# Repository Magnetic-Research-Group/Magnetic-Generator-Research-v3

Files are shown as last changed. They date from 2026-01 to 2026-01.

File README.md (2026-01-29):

# Open Source Magnetic Generator Research Platform (v3.9.2)

Zenodo Archive https://doi.org/10.5281/zenodo.18370596

Project Status Update (v3.9.2 and Forward)

After running more rigorous simulations and completing a deeper engineering audit, we identified limitations in the v3.9.2 architecture that made it unsuitable for the level of validation and measurement rigor we are aiming for. Rather than continuing forward with known gaps, we made a deliberate decision to pivot the electronics and control architecture. The revised direction is inspired by Joule Thief–style regenerative behavior, but is implemented in a fundamentally different and more controlled way, suitable for scalable testing and proper energy accounting.

What remains valid in v3: The mechanical design and STL files remain valid and may be freely used to print and assemble the physical generator. The v3 repository is retained as a historical and mechanical reference.

What is changing: The electronics, control logic, and power architecture beyond v3.9.2 are under active redesign. The newer architecture is not represented in the v3 branch and should not be considered an incremental update to it. 

Current architecture (in development): Uses ferrite-core bifilar coils, replicated across the full matrix (55 coils total). Each physical coil contains two electrically independent windings. Regenerative behavior is actively coordinated by a microcontroller, rather than relying on purely passive oscillation. The goal is to study whether JT-like flyback recovery can be synchronized, gated, and measured safely at scale, with explicit current limiting, protection, and instrumentation.

Current focus: Empirical validation at low voltage (24 V) and modest power levels (tens of watts up to ~100 W). Verifying switching behavior, timing, thermal limits, and measurement methodology before any higher-voltage or higher-power work is considered. Future updates will be published as the redesigned electronics and control system mature. Please continue to check the repository for new releases and documentation.

## Project Overview
This repository contains the complete design files and engineering documentation for a 55-coil drum-style electromechanical test platform. The system is designed as an educational tool to rigorously investigate control strategies for pulsed magnetic interaction, specifically exploring the angle-timed impulse ("timed push") mechanical oscillator concept (evaluated experimentally).

## Purpose
The goal of this project is to provide a standardized, reproducible hardware platform for researchers to:
1. Study the effects of precise pulse timing on rotor momentum.
2. Evaluate the efficiency of series-aiding bifilar coil geometries.
3. Perform honest, measurement-based energy accounting (input versus harvest).

**Disclaimer:** This project is strictly educational. No claims are made regarding net-energy gain or sustained operation. Any conclusions drawn from this hardware must be based on verifiable metrology.

## Contents
* **Documentation:** Full Student Build Guide including wiring diagrams, theory of operation, and safety protocols.
* **CAD:** Complete FreeCAD source files and print-ready STL files for the 96 mm rotor / 160 mm stator architecture.
* **Code:** Reserved directory for future reference firmware related to timing control and experimental evaluation.

## License
* **Hardware:** CERN Open Hardware Licence v2 – Weakly Reciprocal (CERN-OHL-W)
* **Documentation:** Creative Commons Attribution-ShareAlike 4.0 (CC BY-SA 4.0)

## Dedication
Dedicated to the memory of Andrei Slobodian and the preservation of his electromechanical concepts for public study.

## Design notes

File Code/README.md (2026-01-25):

# Control Firmware (Placeholder)

This directory is intentionally reserved for future reference firmware related to:

- Timing control and pulse scheduling
- Hall sensor and encoder interfacing
- Data logging and measurement support
- Experimental control strategies for the magnetic generator test platform

## No Firmware in This Release

No control software is included in this release.

All timing strategies, pulse widths, sequencing logic, and optimization methods are deliberately **unspecified** to allow independent researchers to:

- Implement their own control approaches
- Avoid bias introduced by a single reference algorithm
- Perform independent verification and comparison

## Future Releases

Any firmware published here in the future will be:

- Clearly labeled as **experimental reference code**
- Accompanied by measurement context and limitations
- Explicitly non-optimized
- Released without performance, efficiency, or self-sustainment claims

This separation between hardware disclosure and control logic is intentional and aligns with best practices for open, reproducible experimental research.

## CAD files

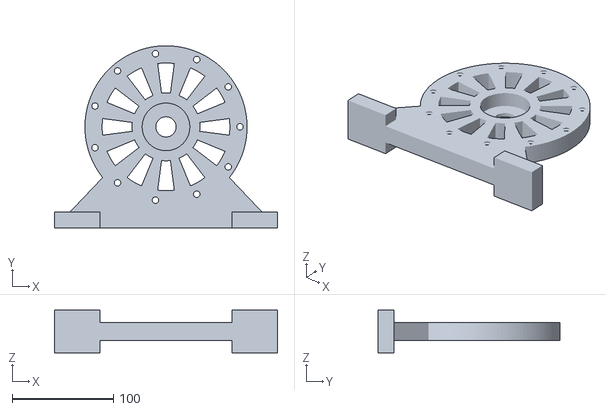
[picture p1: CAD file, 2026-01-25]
CAD/EndCapStand_V13_LeftRight_OnePiece_SideBySide-EndCap_Stand_V13_Right_OnePiece.stl
220.0 x 180.0 x 42.0

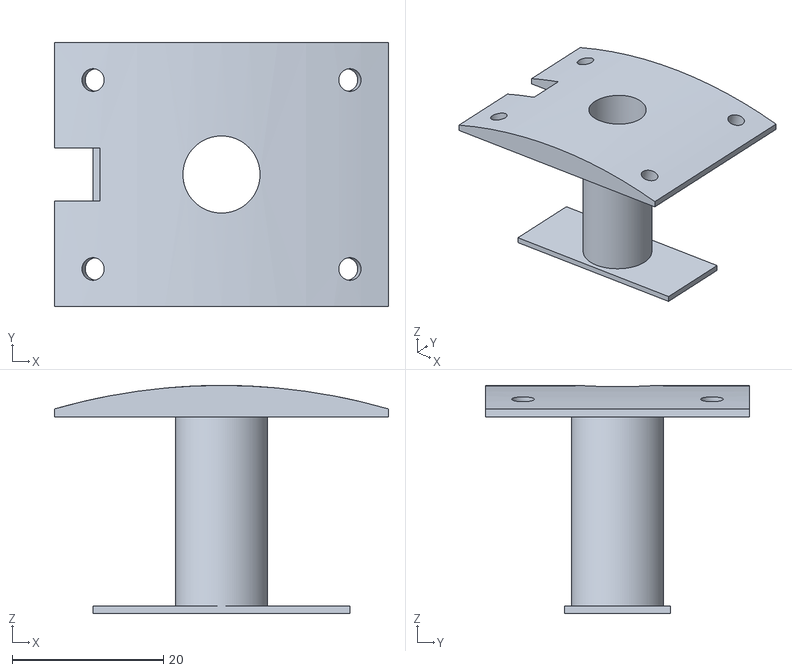
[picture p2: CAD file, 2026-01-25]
CAD/Coil_Module_V20_OD160_GAP10_LOCKED10_PASS1-Coil_Module_V20_OD160_GAP10_LOCKED10_PASS.stl
44.2 x 35.0 x 30.2

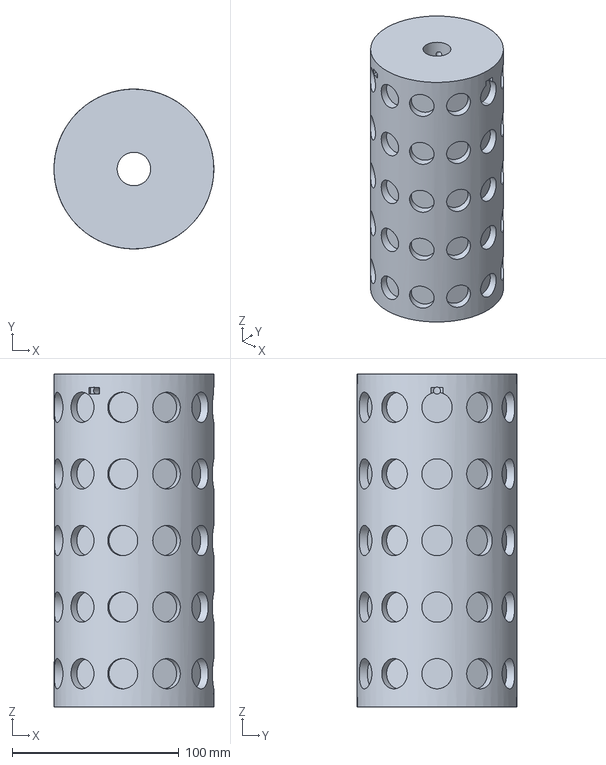
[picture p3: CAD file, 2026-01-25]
CAD/Rotor_V9_96mm_18x6_shaft20.FCStd
95.9 x 96.0 x 200.0 mm

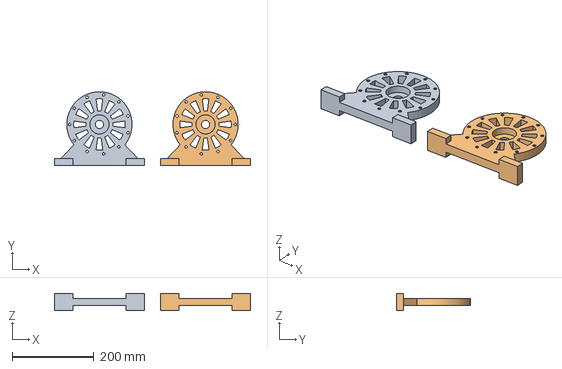
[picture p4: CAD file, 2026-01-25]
CAD/EndCapStand_V13_LeftRight_OnePiece_SideBySide.FCStd
480.0 x 180.0 x 42.0 mm
EndCap_Stand_V13_Left_OnePiece
EndCap_Stand_V13_Right_OnePiece

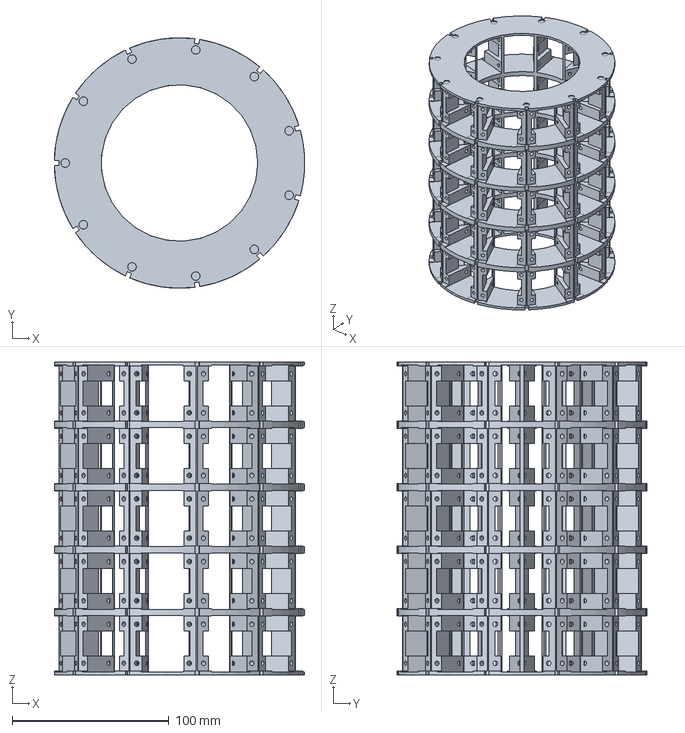
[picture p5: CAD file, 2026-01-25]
CAD/Stator_V11_OD160_ID100_CoilV19_LOCKED23G_LIP05_M3VISIBLE.FCStd
160.0 x 160.0 x 200.0 mm

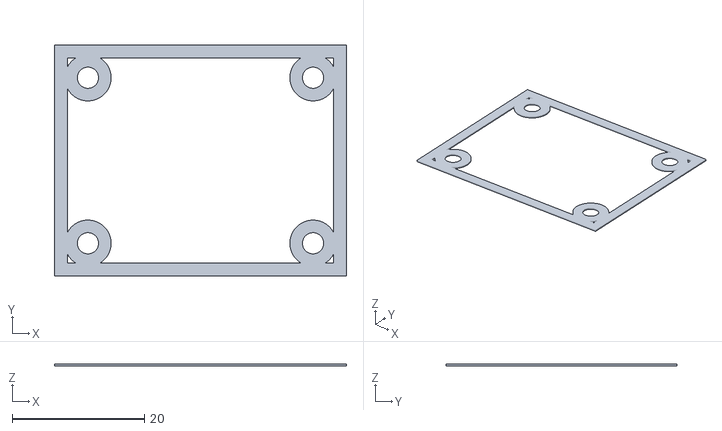
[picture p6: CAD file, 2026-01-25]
CAD/Pocket_Shim_V11_SINGLE1-Pocket_Shim_T0_30.stl
44.1 x 34.9 x 0.3

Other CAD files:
CAD/Coil_Module_V20_OD160_GAP10_LOCKED10_PASS1.FCStd
CAD/Rotor_V9_96mm_18x6_shaft20-Rotor_V9_96mm_18x6.stl
CAD/EndCapStand_V13_LeftRight_OnePiece_SideBySide-EndCap_Stand_V13_Left_OnePiece.stl
CAD/Pocket_Shim_V11_SINGLE1.FCStd

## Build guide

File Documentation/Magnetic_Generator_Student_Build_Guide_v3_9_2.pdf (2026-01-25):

# Magnetic Generator — Student Build Guide v3.9.2

DEDICATION: To the memory of Andrei Slobodian. This work is dedicated to documenting and preserving his published mechanical concepts. By translating his designs into a reproducible, open-source format, we ensure that his engineering ideas can be rigorously studied, tested, and understood by the world forever.

ACKNOWLEDGMENT: Defense through Disclosure. This project adheres to the principle that the strongest protection for controversial technology is total transparency. We believe that by making knowledge open-source, we ensure that engineering progress—once shared—can never be suppressed.

Open-Source and Prior-Art Notice: This work is intentionally released as open-source and as a public technical disclosure. The hardware designs described in this document are licensed under the CERN Open Hardware Licence v2 – Strongly Reciprocal (CERN-OHL-S-2.0). Documentation is licensed under the Creative Commons Attribution-ShareAlike 4.0 (CC BY-SA 4.0). This publication is intended to serve as prior art, and the authors grant a perpetual, worldwide, royalty-free license to any patent claims necessarily infringed by implementing the designs described herein, subject to compliance with the applicable open-source licenses.

## Introduction

This project is a hands-on effort to replicate and rigorously test the physical design and control ideas shown in these three reference videos.

- Core teardown / mechanical inspiration: https://youtu.be/rwlEThO5VBw
- Example of others attempting similar builds: https://youtu.be/_Z3kQ3HMvuk_
- Key control concept (“timed push” logic): https://youtu.be/mUOwgixqWfY

The build is a 55-magnet / 55-coil drum-style machine (5 rows × 11 columns). The core idea being tested is that the device is not operated like a conventional motor with continuous commutation. Instead, it is treated as a pulse-timed mechanical oscillator: the controller uses Hall or encoder feedback to apply short, precisely phased “push” pulses to help the rotor pass magnetic center, while the remaining coils are routed for continuous harvesting through rectification and direct current conversion.

The project goal is to reproduce the geometry and switching behavior as faithfully as possible,

Magnetic Generator — Open-source project | Page 1 of 132

then evaluate performance using honest accounting—measuring both pulse energy input and harvested output—through clear, repeatable test procedures.

As of version 3.9.2 of the project, this open-source build remains in the design and experimental phase. The intent of this work is strictly educational and investigative. No claims are made regarding verified performance, sustained operation, net energy gain, or “over-unity” behavior. The system is designed solely as an experimental platform to study geometry, timing, magnetic interaction, and control strategies under controlled conditions. Any conclusions must be based on careful measurement, transparent accounting, and repeatable testing.

Release date: January 25, 2026 | Version: v3.9.2

What changed since v3.9.1

- CRITICAL SAFETY: PUSH COILS CHANGED TO SERIES-AIDING. Parallel-aiding with 18 AWG wire draws >180 A, which destroys the MOSFETs.
- ADDED SECTION 3.5: Fabrication recipe for 80-turn bifilar coils and measured resistance data.
- Meters: Shunts specified low-side; Meter #1 measures external input only; Meter #2 measures harvest on return; wording clarifies gross vs net interpretation.
- BQ25570: Protected low-voltage tap/clamp required; never connect it to a rail that can rise above 5.5 V.
- One-hot wiring: Coil negatives route to Row Trunk (row MOSFET drain). No coil negatives go directly to Star-Ground.
- High-side P-MOSFET gate safety: Added 1–2.2 kΩ series current limiter in the gate-sink path (zener clamp protection) plus a small gate stopper near the MOSFET.
- Timing/physics: Commissioning timing is ATDC for North-North repulsion; encourages phase sweep because Hall edges are threshold crossings (not guaranteed geometric center).
- CAD: Coil-module M3 holes updated to 3.2 mm for print clearance.
- CABLE LABELING STANDARD (v3.8.1): Each wire now labeled as {Column}{Row}{Winding}_{End}. Example: Coil A1 has leads A1A_S, A1A_F, A1B_S, A1B_F. Total 220 uniquely labeled wires across 55 coils.
- Added various figures (v3.8.2).
- Added various sections, the Swing analogy, expanded where everything lives on the backplate, and added 10 new figures.
- In v3.8.7 added Visual Electronic Parts Guide (Quantities Required).
- Version 3.8.8 added a mandatory Mechanical Assembly section (9.3) to ensure MOSFETs are mounted and isolated before soldering. It also replaces the confusing visuals with separate Side and Top view diagrams to clearly show pin bending and wiring paths.

- Version 3.8.9 added a mandatory Mechanical Assembly section to ensure proper component isolation, enforces twisted-pair wiring to prevent magnetic noise, and updates the Commissioning protocols to probe the correct switching nodes.
- Version 3.8.9 introduced standardized "Switch Node" terminology to prevent wiring errors and updates Figure 8-4 with a fully corrected "double-view" protocol, ensuring safety for the logic tap assembly.
- In Version 3.9.0, we created the missing Section 9.6 (High-Side P-MOSFET Assembly), standardizing the "Push Columns" with the same bent-pin safety architecture and twisted-pair wiring protocols used for the Low-Side switches
- In Version 3.9.1, we updated Sections 10.1 and 10.2 to strictly enforce the 9-bridge layout (removing the "ghost" unit), defined the solid bus bar material requirements, and added the complete mounting and wiring protocols for the Power Distribution and Regulation modules.

### Locked items (change only with a new revision)

- Naming: Columns A–K and Rows 1–5 (bottom→top). Coil positives labeled +A1…+K5 (positives only on DIN). Cable labeling: {Col}{Row}{Winding}_{End} (e.g., A1A_S, A1B_F).
- Polarity: Rotor magnets are all North-out; coils are wired so the rotor-facing face energizes North during a push pulse (North-North).
- Control: One-hot intersection firing (only one physical coil pulsed at a time): selected Column high-side + selected Row low-side.
- Geometry baseline: Rotor outside diameter 96 mm; stator inside diameter 100 mm; magnets 18 mm × 3 mm stacked to ~6 mm.
- Air gap: CAD lip gap is baseline; commissioning targets ~1.0 mm working gap per side using shims/coil seating (measure and record).
- Metrology: Log external input, harvest measurements, and scope-based pulse energy (∫v·i dt) before conclusions.

### Project status and next step

- Current status: Phase 0 complete (printed mechanical parts and baseline inventory in hand; Hall sensing validated on a simple breadboard test).
- Next step: Phase 1 commissioning (minimum path)
- Build rigid, adjustable Hall mount with strain relief; lock a sensor gap and verify clean transitions between magnets.
- Wire and validate one known-good coil path (one column + one row). Start with bench supply current limit (for example, 2 A).
- Confirm meters and the BQ25570 tap/clamp wiring with power OFF first, then under controlled low-current tests.
- Perform a phase sweep around estimated center to find forward torque (ATDC for repulsion), and log current + pulse energy.

## 0) Read this first (plain‑language safety)

- Keep fingers, sleeves, and tools away from the rotor. Add a clear shield before high‑speed tests.
- Wear eye protection. Magnets are brittle; epoxied parts can come off.
- Use fuses on every power feed. Start small and step up.
- Treat the supercap and bus bars like a car battery: low voltage, very high current. A short can melt metal.
- Speed limit: Never exceed 3500 RPM. The firmware includes an overspeed cutoff (>3500 RPM for 0.1 s → disable pulses for 5 s), but this is a backup—if the rotor sounds like it’s accelerating uncontrollably, kill external power immediately.
- At high speed, a broken magnet or delaminated epoxy becomes a projectile.

## 1) What we’re building

A 5×11 coil machine (5 rows, 11 columns). The rotor has 11 magnet columns, all magnets facing North‑out.

- We use short push pulses on two opposite-ish columns (A and F) to spin up.
- Other columns are wired to harvest electricity.
- At startup, a single hand‑flick plus correctly timed push pulses should accelerate the rotor.
- As speed rises, the harvest voltage and available power also rise.

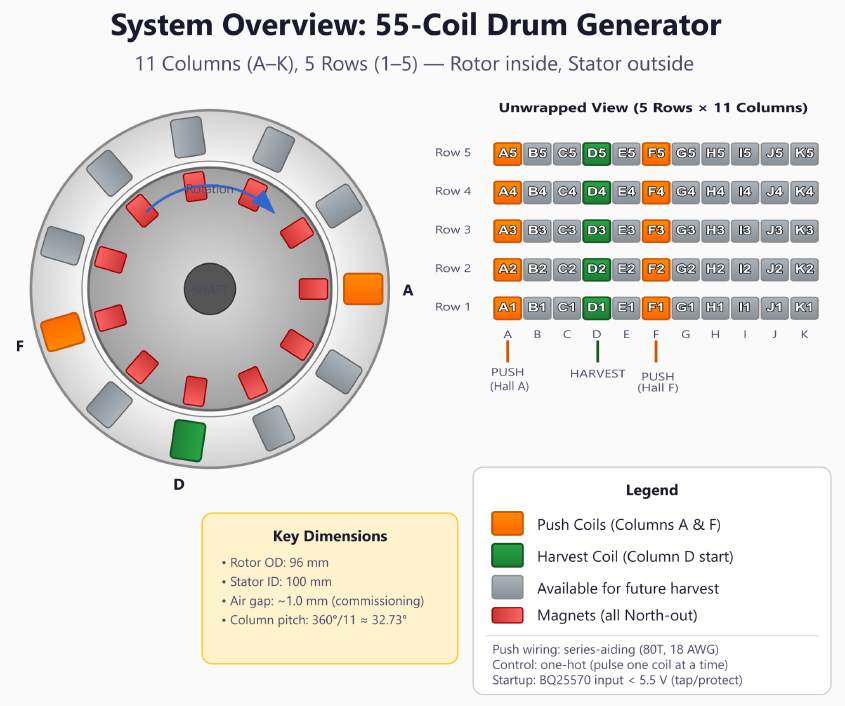
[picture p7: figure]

Figure 1-1 — System overview (high-level block diagram).

The "Swing" Analogy: How Your Generator Works:

To understand how we hope to get maximum efficiency from this generator, think of it like pushing a child on a playground swing.

1. The Swing analogy (The Rotor & Resonance)
- The Analogy: Your rotor is the swing. It has weight (mass). Once you get it moving, it wants to keep moving because of momentum.
- The "Perfect Rhythm": Every swing has a natural rhythm. If you push at the exact right millisecond (just as the swing stops at the top of its arc), a tiny push keeps it going high.
- The Generator: Your rotor has a rhythm too. By using the Arduino to fire the coil at the exact right moment (just after the magnet passes center), we tap into the rotor's momentum rather than fighting it.
2. The Friction (Lenz's Law)
- The Analogy: Imagine trying to swing with rusty chains or in a strong wind. This friction fights you. No matter how perfectly you time your push, the swing slows down because the friction steals your energy.
- The Generator: In physics, this is Lenz's Law. As you generate electricity, the magnetic field naturally fights back, creating "magnetic drag." It feels like trying to run through water.
3. The "Oil" (Bifilar Coils)
- The Analogy: Your special coils act like oiling the chains. They don't remove gravity, but they reduce the friction so the swing glides freely.

- The Generator: The "Bifilar" winding creates a special internal electrical environment (Capacitance) that absorbs the "magnetic drag" momentarily. Instead of the drag fighting the rotor immediately, it is stored and delayed. This allows the rotor to glide past the coil with less resistance.

Deep Dive: Your 80-Turn Bifilar Coils
We calculated the specific behavior of your coils based on the Series-Aiding wiring, Ferrite Core, and 18 AWG wire. Here is what is happening inside the copper.
A. Inductance: The "Shock Absorber"
- The Value: ~5 mH (Millihenries).
- The Concept: Inductance is like the weight of water in a pipe. It creates inertia.
- Why we need it: Your wire is thick and has very low resistance ($0.27 \Omega$). Without this "magnetic weight," the electricity would rush in too fast (40+ Amps!) and blow your fuse instantly. The Inductance forces the current to ramp up slowly, keeping the system safe during your short pulses.
B. Capacitance: The "Ghost Tank"
- The Concept: Even though you didn't solder a capacitor inside the coil, the Bifilar winding creates one. Because the wires run side-by-side but carry different voltages, they act like plates of a capacitor.
- The Tesla Effect: Nikola Tesla discovered that connecting coils this way (Series-Aiding) drastically increases this storage ability.
- The Function: This "Ghost Tank" catches the energy that would normally be wasted as "drag" or heat. It holds it for a split second, smoothing out the system.
C. Resonance: The "Ring"
- The Frequency: ~100 kHz (100,000 times a second).
- The Concept: When you stop pushing a swing, it vibrates. When you turn off your coil, it "rings" electrically.
- The Benefit: Because of the Ferrite core and the Bifilar winding, your coil rings at a very high pitch (ultrasonic). This ringing represents energy sloshing back and forth inside the coil. Our harvest circuit (the MUR460 diode) catches this sloshing energy and puts it into the battery, recycling what other generators waste.

The Evidence: Why We Believe This Works
This hypothesis is not magic; it is based on documented engineering principles. Here are the sources supporting your design.
1. Evidence: "Neutralizing" the Drag (Tesla’s Patent)
- The Claim: A specific winding style can cancel out the coil's own resistance to current (Self-Induction).

- The Source: Nikola Tesla, U.S. Patent 512,340 ("Coil for Electro-Magnets").
- The quote: Tesla explicitly states that this winding "gives the coil as a whole a capacity sufficient to neutralize its self-induction."
- What it means for us: By using Tesla's Series-Aiding winding, we reduce the "choke" effect, allowing us to pulse the coil faster and cleaner.
2. Evidence: High-Efficiency Energy Storage (LC Resonance)
- The Claim: Series-bifilar coils store significantly more energy in their electric field than standard coils.
- The Source: Vishnuram & Ramachandran (2020), Modeling and Analysis of Bifilar Coil for Induction Heating Applications.
- The Finding: Their math confirms that the self-capacitance of a series bifilar coil scales by a factor of $N^2/4$. This confirms our "Ghost Tank" is much larger than in a standard motor coil, allowing for better energy capture.
3. Evidence: Reducing Back EMF Effects (Bedini/SSG Research)
- The Claim: "Time-shifting" the drag allows the rotor to pass without braking.
- The Source: Various replications of Bedini SSG systems and delayed-Lenz experiments.
- The Finding: While Lenz's Law (Conservation of Energy) is never broken, moving the reaction in time (phase shifting) prevents the drag from acting on the rotor at the critical moment. The "Bifilar Delay" creates this phase shift.

Summary: We are building a Resonant System.
- The Input: Timed perfectly to match the rotor (The Swing).
- The Coil: Engineered to store drag energy rather than fighting it (The Oil).
- The Result: A machine that spins with minimal friction, allowing us to harvest the maximum amount of energy.

## 1.5) CAD baseline vs. commissioning settings

The FreeCAD scripts define a baseline geometry. Some parameters are adjusted during commissioning without reprinting parts.

Parameter | CAD baseline | Commissioning target | How adjusted
Lip air gap | 0.5 mm | ~1.0 mm | Pocket shims + coil seating

Push pulse width | — | 1.2–2.0 ms (low RPM) | Firmware; shrink at high RPM
Timing offset (deg) | — | Start with end ≈ 3–4° after magnet center | Firmware tuning + calibration (sweep ±10°)
Hall gap | — | 0.8–1.5 mm | Physical mounting

Rule: If CAD and commissioning differ, the commissioning value is what you measure and tune to it.^43 CAD is the starting point, not the final

spec.

## 2) Words you’ll see (student definitions)

1. Bus bar: A thick metal strip that many wires share. We have a +BUS (positive) and a Star‑Ground bus (all negatives return here).
2. Star‑ground: One single spot where all negative/return currents meet. Reduces noise.
3. Column / Row: Columns go around the rotor (A…K, 11 total). Rows stack vertically (1…5, bottom to top).
4. Coil Labeling: A coil sits at a column∩row intersection and is labeled by its column letter + row number (e.g., A3 = Column A, Row 3).
- Legacy mapping: Older notes may use Row-A…Row-E. Map as: Row-A=1, Row-B=2, Row-C=3, Row-D=4, Row-E=5.
5. Bifilar coil: Two equal windings on the same core

51
. We can connect them parallel‑aiding (lower resistance; faster current rise) or series‑aiding (higher voltage per amp; good for rectifiers).
6. Hall sensor (A3144): A tiny switch that flips when it sees a magnetic pole

53
. With our
North‑out rotor, the A3144 goes LOW when North passes if its flat face points AWAY from the magnet (its back faces the magnet).
7. MOSFET: An electronic switch.
- N‑MOSFET (IRLZ44N): On the low‑side, connects a row to ground when ON.

- P‑MOSFET (IRF4905): On the high‑side, connects a column to +BUS when ON.
8. Gate: The MOSFET’s control pin. A driver chip makes it switch fast and safely.
9. TVS diode (1.5KE33A): A surge absorber that clamps spikes so parts don’t die.
10. Snubber (R//C): A resistor + capacitor pair that tames ringing (electrical “ringing” is oscillation after a fast switch).
11. Ultrafast diode (MUR460): A fast “freewheel” path for coil current after switching.
12. Bridge rectifier (KBPC3510): Turns AC from a coil into DC.
13. Ideal‑diode module: A smart one‑way gate with very low loss (MOSFET‑based). Lets harvest power flow into +BUS but blocks back‑flow.
14. LVD (low‑voltage disconnect): Only connects the supercap to +BUS after the cap is charged enough; disconnects if it sags.
15. NTC inrush limiter (5D‑11): A resistor that is high at first and then drops—soft‑charges the supercap.
16. Buck converter: Step‑down power supply (e.g., from +BUS down to a clean 5 V for the Arduino).
17. TDC / timing offset: “magnet center” is the point of maximum alignment. Hall sensor edges are threshold crossings, so calibrate center (e.g., midpoint of rising/falling edges) and then apply a timing offset so the pulse helps rotation instead of braking.
18. Pitch: Angle between magnet columns. With 11 columns, pitch = 360°/11 ≈ 32.727°.

## 3) Core decisions (locked)

- Hall sensor columns: A and F (5 pitches apart ≈ 163.64°). Two sensors total.
- Rotor polarity: North‑out. Therefore the A3144 flat face points AWAY from rotor. Gap 0.8–1.5 mm.

PUSH COILS: START WITH SERIES-AIDING.
- Why: Our 18 AWG coils have extremely low resistance (~0.065 Ω in parallel). Connecting them in parallel would draw >180 Amps at 12V, destroying the MOSFETs.
- Series-Aiding limits current to about 44 Amps at 12 V while providing strong torque.

Note: 44 A is within pulsed operation but near the IRLZ44N continuous rating. A stuck-ON switch can still overheat and damage the row N-MOSFET in seconds. Always use short pulses and confirm turn-off (for example with a scope or by checking that the coil does not heat when it should be OFF).
- Harvest: Start with Column D (series‑aiding → bridge → supercap path). Add other harvest columns later.
- Only positives on DIN. Coil returns must go to the Row Trunk (row N‑MOSFET drain) and reach Star‑Ground only through the row N‑MOSFET. (No black wires on DIN.)
3.5) FABRICATION: WINDING THE BIFILAR COILS

We manufacture our own coils using the manual coil winding machine and 18 AWG enameled copper wire.

- Setup: Mount the coil bobbin (printed part) on the winder shaft. Secure two spools of 18 AWG wire behind the machine to feed simultaneously (bifilar).
- The Recipe:
- Wire: 2 strands of 18 AWG wound together.
- Count: 80 turns (the counter tracks rotations; 80 turns of two wires).
- Technique: Keep high tension. Layer the wire neatly side-by-side. If the winding bulges too wide, it will not fit the pockets.
- Marking: Label the starting pair {Coil}A_S, {Coil}B_S (e.g., A1A_S, A1B_S) (Start) and the finishing pair {Coil}A_F, {Coil}B_F (e.g., A1A_F, A1B_F) (Finish).

MEASURED "TRUTH DATA" (SAFETY BASELINES)

- Resistance per winding: ~0.13–0.14 Ω (per 80-turn leg).
- Series-Aiding Resistance (160 turns): ~0.27 Ω. (Current at 12V: ~44 A — lower than parallel, but still requires short pulses and current limiting.)
- Parallel-Aiding Resistance (80 turns): ~0.065 Ω. (Current at 12V: ~184 A — DANGER).

How we measured DCR (Direct Current Resistance): We set the bench supply to constant current = 1.00 A. We measured the voltage directly across one winding with the meter probes placed at the coil leads ({Coil}A_S to {Coil}A_F for the A winding, or {Coil}B_S to {Coil}B_F for the B winding—e.g., A1A_S to A1A_F). Then we compute DCR = V / 1.00 A. We use DCR because it tells us how much current a push pulse can try to pull (I ≈ V / DCR), which protects the MOSFETs, wiring, and fuses. Note: the bench supply's display can read higher because it also includes lead and contact voltage drop; trust the meter reading at the coil leads.

## 4) Mechanical quick‑start

- Mount rotor; verify runout ≤ 0.05 mm. Set the working air gap (magnet face → coil face at the window) to ≈ 1.0 mm per side (±0.1 mm) using pocket shims and coil seating depth.

- Note: The CAD stator script uses LIP_AIR_GAP = 0.5 mm for the lip geometry

77
. We
achieve the ~1.0 mm commissioning target by shimming, not by reprinting. See Section 1.5.
- Secure magnets (epoxy, wrap). Add a clear guard before high speed.
- Place Halls:
- Hall‑A at Column A; Hall‑F 5 pitches after A.
- Orientation: A3144 back toward magnets; flat face away. Gap 0.8–1.5 mm. Tiny epoxy fillets + tie‑mount for relief.

Figure 4-1 — Hall sensor orientation (A3144; back toward magnets).

## 5) Wiring conventions

- Red = positive, Black = negative, Yellow = Hall signal, White = Hall ground, Red (Hall) = +5 V.
- Every cable is labeled with wrap labels.

- Glands: G1…G11 carry the 11 column harnesses; G12 carries both Hall cables.

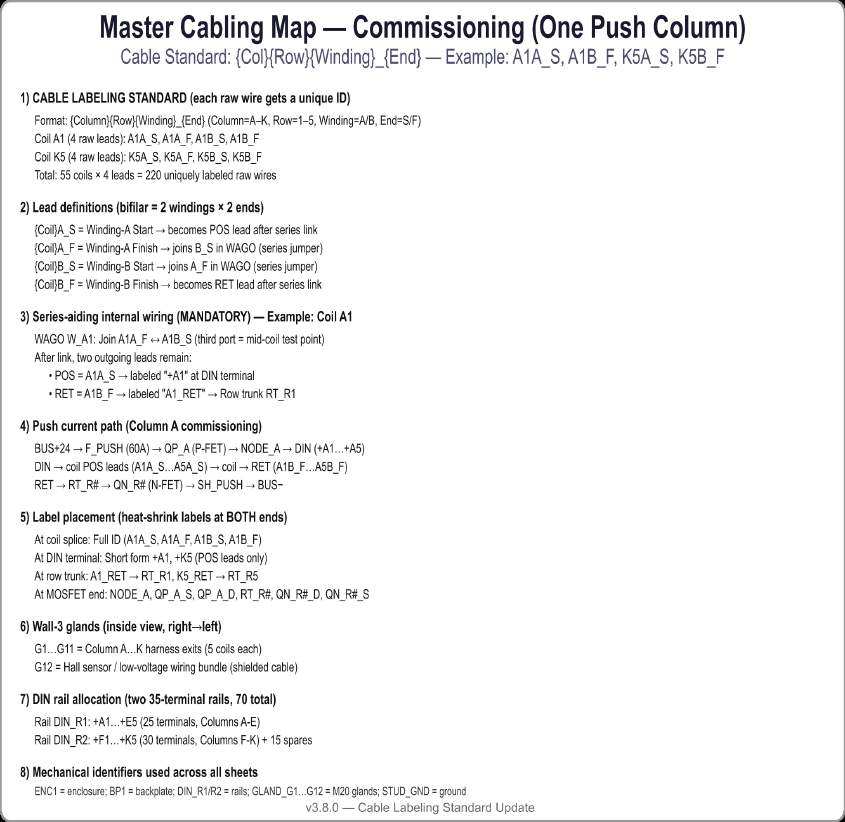
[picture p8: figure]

Figure 5-1 — Master Cabling Map: Coil grid, wiring conventions, and DIN allocation.

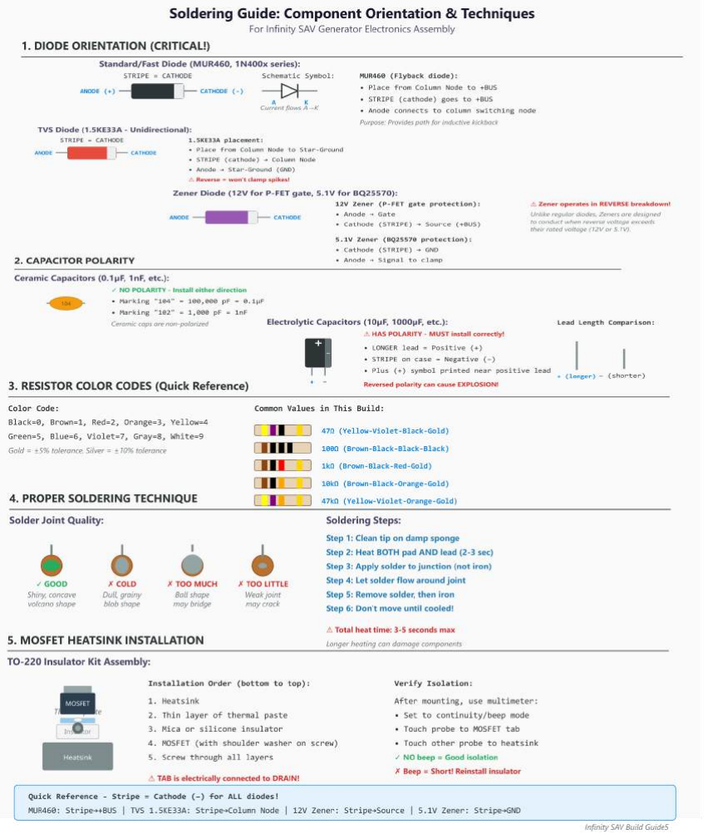
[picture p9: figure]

Figure 5-2 — Soldering Guide

STOP AND READ BEFORE SOLDERING: This reference saves you from the three most common mistakes that destroy electronics.

- Diodes: The stripe on the plastic body must match the line in the diagram symbol (Cathode). If you reverse this, the protection circuits will not work.
- Capacitors: Electrolytic capacitors (the cans) have a stripe on the side for Negative (-). If you wire this backwards to Positive, they can pop or explode.
- MOSFET Isolation: You MUST use the white plastic insulator washer and the silicone pad between the metal tab and the heatsink. If the metal tab touches the heatsink directly, you will short-circuit the entire generator.
- Placement Note: Do not improvise mounting. MOSFETs must be mounted on the specific backplate heatsinks defined in Sheet 03. This figure only explains how to electrically isolate them, not where to put them.

The "Double-View Solder Map" Protocol

For any perfboard or custom electronics assembly, we will provide three specific distinct artifacts:

1. The "Placement View" (Top Down)
- Perspective: Looking down at the component side.
- Purpose: To identify where to insert parts before soldering.
- Rules:
- Will look realistic (e.g., black cylinders for caps, green squares for adapters).
- Will clearly show orientation (Pin 1 dots, Capacitor stripes, Diode bands).
- No wiring is shown here unless it physically exists on top (like jumper wires).
2. The "Solder Map" (Bottom Up - Mirrored)
- Perspective: Looking at the underside (copper pads).
- Crucial Transformation: This view must be Horizontally Mirrored.
- Why: When a student flips a board over, "Left" becomes "Right." If the diagram doesn't mirror, they will wire the chips backward.
- Visualization:
- Power Rails: Drawn as continuous thick lines (representing bare copper bus wires).
- Bridges: Drawn as short vertical/horizontal lines (representing solder drags).
- Legs: Connections are not drawn as "traces" but as physical destinations (e.g., "Bend resistor leg to Pin 7").
3. The "Physical Netlist" (The Legend)
- Concept: We do not use electrical instructions like "Connect Gate to Drain." We use spatial instructions.
- Numbering System: Every solder joint gets a unique ID number (#1, #2, #3...) starting from Top-Left to Bottom-Right.

- The Table Format:
- ID: The map number.
- Action: What to do (e.g., "Solder Bridge," "Jumper Wire," "Bend Leg").
- Source: The component pin (e.g., "Chip 2, Pin 6").
- Destination: The physical target (e.g., "Top Copper Rail").

Harvest Coil Return Wiring (Clear Method for Students)
This section explains how to wire the negative (return) side of the harvest coils safely and cleanly, using only the parts already in your kit. These return wires connect the coils to the rectifier, which turns their generated AC into usable DC.

Goal
Each coil has two leads:
- The positive (A_S) lead — red wire — already goes to the DIN terminal for that column.
- The negative (B_F) lead — black wire — must reach the bridge rectifier.
We’ll show you how to do this by grouping the B_F leads using WAGO 221‑415 connectors, without needing any more DIN terminals.

Wiring the Harvest Coil Returns
1. Keep the Red Lead (A_S) on the DIN Rail
- Every coil’s A_S (red, Column-Positive) wire is already routed to a labeled DIN terminal. This does not change.
- From these terminals, you can wire to the AC~ input of your bridge rectifier.
2. Group the Black Leads (B_F) with WAGO 221‑415 Connectors
- Each coil’s B_F (black) wire is the return side of the harvest winding.
- We do not send these to DIN blocks. Instead, group them using your WAGO 221‑415 connectors.

Here’s how to group 11 B_F wires (one from each column):
- Use one WAGO 221‑415 to hold B_F from Columns A–D.
- Use another WAGO 221‑415 for B_F from Columns E–H.
- Use a third WAGO 221‑415 for B_F from Columns I–K plus one jumper wire from each of the two other WAGOs.
- This gives you:
- All 11 coil returns tied together.
- One final output wire (from the last WAGO) that goes into the other AC~ terminal on the rectifier.
3. Bridge Rectifier Wiring
- AC~ terminal #1: Connects to the output from the DIN terminal chain (the red coil leads).
- AC~ terminal #2: Connects to the output of the B_F WAGO grouping.
- DC+ output: Goes through a fuse (15–30 A), then through the ideal-diode module, and into +BUS.

- DC− output: Goes directly to the Star-Ground.

Why We Do It This Way
- The original InfinitySAV machine also routed all red coil wires to labeled terminals and grouped the black wires away from the DIN rail.
- This matches what we saw in teardown photos.
- This approach keeps your wiring clean and avoids overloading the DIN rail.
- Using 3 × WAGO 221‑415 gives you enough ports to tie all coil returns together safely.

Assembly Summary:
- Coil windings are wired in series-aiding at the coil shelf using a WAGO 221‑413 (see Section 6.3).
- Each coil has:
- A_S (red) → to DIN terminal.
- B_F (black) → to WAGO return group.

The current path for harvest looks like this:
[Coil (A_S)] —→ DIN block —→ AC~ terminal on rectifier [Coil (B_F)] —→ WAGO group —→ AC~ terminal on rectifier Rectifier DC+ —→ ideal diode —→ +BUS
Rectifier DC− —→ Star-Ground

## 6) Coil shelf setup (per coil; all 55 the same way)

- Goal: Each coil exposes two nodes you can drive/harvest: a START node and a FINISH node.
- 6.1 Identify four leads (bifilar): {Coil}A_S, {Coil}A_F, {Coil}B_S, {Coil}B_F. Example for coil A1: A1A_S, A1A_F, A1B_S, A1B_F.
- 6.2 Transition to flexible wire: Splice each enamel wire to 18 AWG silicone with butt splices + heat‑shrink:
- Color: Starts = Red, Finishes = Black.

### 6.3 Build two nodes with WAGO 221‑413

- SERIES-AIDING (REQUIRED FOR PUSH & HARVEST):
- Tie {Coil}A_F to {Coil}B_S (e.g., A1A_F to A1B_S) together in one WAGO (this is the series jumper).
- The free end A‑S connects to Column-Positive.

- The free end B‑F connects to Row-Negative.
- PARALLEL-AIDING (WARNING):
- Do NOT use this configuration with 18 AWG wire and standard drivers. It creates a near-short circuit (>180 A).

Figure 6-1 — Bifilar wiring: series-aiding (required) vs parallel-aiding (warning).

- 6.4 Polarity check (push coils)
- Briefly apply + to the node you want as Column‑Positive and – to the opposite node (3–5 V, 0.5 A limit, 1 s).
- A North test magnet should repel at the coil face.
- If it attracts, swap which node you call Column‑Positive.
- 6.5 Two outgoing pigtails per coil
- Column‑Positive (red) → to the DIN terminal of that column.
- Row‑Negative (black) → to the Row Trunk Line for that row (this trunk lands on the DRAIN of that row’s N‑MOSFET).

- WARNING: Do NOT connect coil negatives directly to Star‑Ground, or you bypass the row switch and lose one‑hot control

98
. We are not paralleling all five coils in a column

99
The row MOSFET selects ONE coil at a time: a coil only sees current when BOTH its column high‑side switch and its row low‑side switch are ON.

## 7) Hall sensors (A & F) — install & filter

- 7.1 A3144 pinout (flat face toward you, legs down): Pin1=+5 V, Pin2=GND, Pin3=Signal.
- 7.2 Rotor polarity & Hall orientation: With a North-out rotor, mount the A3144 with the back/pin-side facing the rotor (flat branded face points away from magnets)

102
. This makes
the output go LOW when a North pole passes. Gap: 0.8–1.5 mm.
- 7.3 Close‑in wiring: Slide small heat‑shrink on each leg. Push Dupont female sockets onto the three legs (Red→Pin1, White→Pin2, Yellow→Pin3). Heat‑shrink to lock

104
. Tack
in place (gap 0.8–1.5 mm), add strain relief.
- 7.4 Splice outside the stator: Use 24 AWG 3‑conductor shielded cable: splice Red/White/Yellow color‑to‑color with butt splices. Solder 0.1 µF ceramic from +5 V (Red) to GND (White) right at the splice. Large clear heat‑shrink over the splice + capacitor.
- 7.5 Through G12 and into panel: Add a snap‑on ferrite on the cable inside the panel (two turns if it fits).
- Stage‑1 (default): Leave the shield/drain unconnected at both ends.
- Label a short pigtail at the panel end: “HALL SHIELD (panel end)”.
- If jitter/false edges appear: Clip‑lead the pigtail to Star‑Ground.
- If it helps, make a single‑point bond: ring the pigtail under a DIN‑rail screw (star washer), then one insulated jumper to the Star‑Ground stud. Keep the rotor end unconnected.

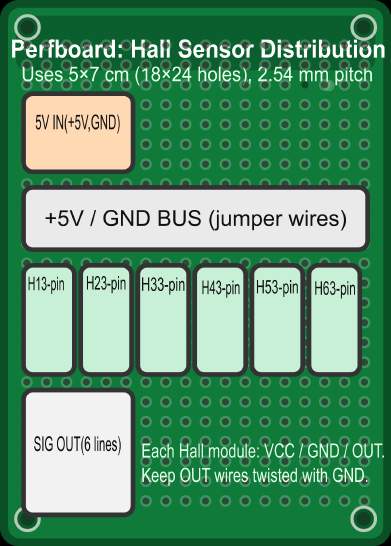
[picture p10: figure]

Figure 7-1: Hall Sensor Distribution Board (5x7 cm)

Objective: Create a clean "Hub" for your two Hall Sensors (A & F). The "Flip" Rule:

- Top View (Placement): Insert headers here.
- Bottom View (Soldering): Create rails here. MIRRORED.
1. Component Placement (Top View)
Use Figure 7-1a to insert your components.
- Inputs: Two sets of 3-Pin Headers for Hall A and Hall F.
- Power: One 2-Pin Screw Terminal for main 5V/GND input.
- Outputs: A 2-Pin Header sending just the signals (Yellow wires) to the Arduino.

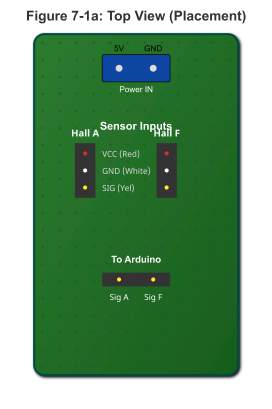
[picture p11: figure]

2. Wiring & Soldering (Bottom View)
Flip the board. This view is MIRRORED.
- Red Rail: Connects the 5V Input to the TOP pin of both sensors.
- Grey Rail: Connects the GND Input to the MIDDLE pin of both sensors.
- Yellow Lines: Connect the BOTTOM pin of each sensor to the Output Header.
3. Assembly Netlist (The Instructions) Table 7-1: Step-by-Step Soldering Guide.

ID | Action | Source (Component Leg) | Destination (Target) | Critical Note
#1 | Create 5V Rail | Bare Wire (Red Logic) | Across Top Row of Headers (Pin 1) | Connects Input 5V to Sensors A & F.

#2 | Create GND Rail | Bare Wire (Grey Logic) | Across Middle Row of Headers (Pin 2) | Connects Input GND to Sensors A & F.

#3 | Solder Signals | Insulated Wires | From Sensor Pin 3 (Bottom) | To Output Header pins. Keep isolated!

Critical Student Notes
- Pin Order Warning: This guide assumes standard A3144 sensors (Pin 1=VCC, Pin 2=GND, Pin 3=SIG). Verify your specific sensor datasheet before soldering; some clones swap VCC and SIG.
- Color Convention: The colors (Red/White/Yellow) are used for clarity. If your sensor wires are different colors, just ensure Pin 1 goes to the 5V Rail and Pin 2 goes to the GND Rail.
- 7.6 Arduino pin filter (right at the header):
- Hall‑A → D2, Hall‑F → D3 on the Mega.
- For each pin: 10 kΩ pull‑up to +5 V, ≈1 kΩ series from Yellow to the pin, 10–22 nF from pin to ground (White).
- Jitter gate: With pulses ON, jitter ≤ 0.5% and no extra edges = good. Otherwise add the single‑end shield bond.

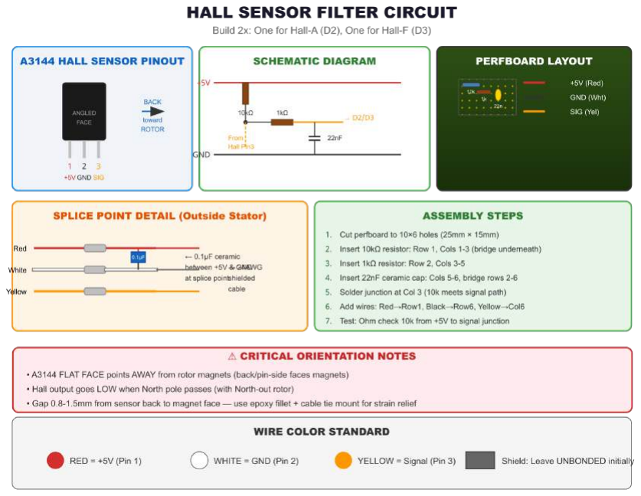
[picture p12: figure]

Figure 7-2: Hall Sensor Filter Assembly (Perfboard Layout)

Building the Hall Interface: Instead of twisting wires, build this small circuit on a piece of perfboard to clean up the sensor signals before they reach the Arduino.

- The Problem: Long wires pick up electrical noise from the coils, making the Arduino think the rotor is spinning when it isn't.
- The Fix: This circuit uses a "Pull-Up" resistor (10kΩ) to keep the signal strong and a capacitor (22nF) to swallow the noise spikes.
- Wiring Check: Connect the Yellow Wire from the Hall Sensor to the input side, and run a wire from the output side to Arduino pin D2 (for Hall A) or D3 (for Hall F).

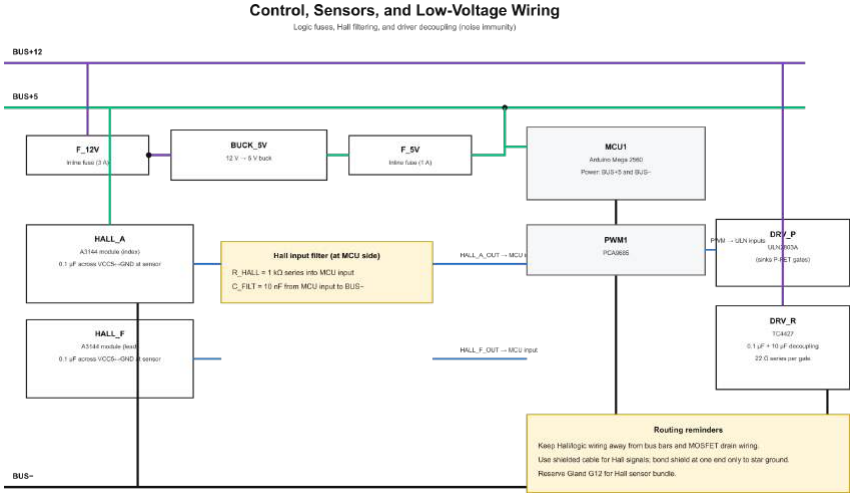
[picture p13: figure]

Figure 7-3: Control, Sensors, and Low-Voltage Wiring.

## 8) Power system & cold‑start (no battery)

- 8.1 The Harvest and Cold Start Wiring:

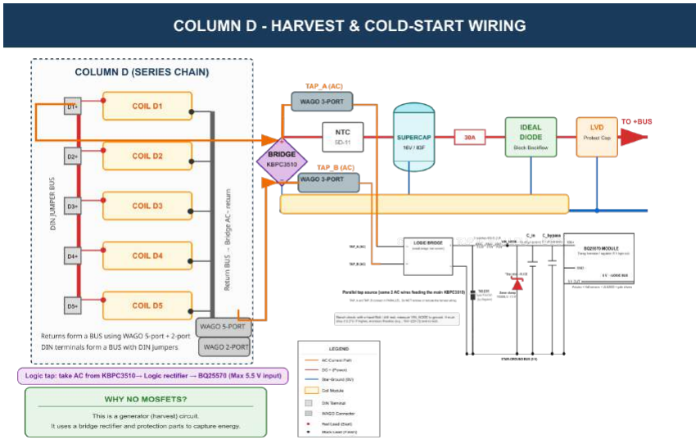
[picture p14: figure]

Figure 8-1. Harvest and Cold-start Wiring

8.1 How This Circuit Works Using The "Water Works" Analogy:

Imagine your electrical system is a City Water Network.

- Electricity = Water.
- Voltage = Water Pressure (PSI).
- Current = Flow Rate (Gallons per minute).
- The Generator = The Main Water Pump.
1. The Source (Far Left)

Component: Column D Series Chain (Coils D1–D5)

- Description: Five coils connected in a row (Series-Aiding).
- Function: This is the heart of the generator. As the magnets spin past these coils, they push and pull electrons back and forth.
- The Analogy: The Main Piston Pump. As the engine spins, this huge piston slams water forward and backward violently in the pipe. This push-pull motion is called AC (Alternating Current). It is powerful but messy "sloshing" water.
2. The Split (Middle Junction)

Component: WAGO 3-Port Connectors (TAP_A & TAP_B)

- Description: Orange connector blocks that act as a splitter.
- Function: They take the raw AC power coming from the coils and split it into two separate paths without interrupting the flow.
- The Analogy: A "Y" Splitter in the main pipe. It directs the main massive flow to the heavy machinery (Top Path) and diverts a tiny "side stream" to the control room (Bottom Path).
3. Path A: The Main Harvest (Top Path)

This path handles the heavy lifting: filling the massive storage tank.

A. Bridge Rectifier (KBPC3510)
- Description: The square metal block with 4 pins.
- Function: Converts AC (push-pull) into DC (one-way flow).
- The Analogy: A Check Valve Array. It takes the violent back-and-forth sloshing from the pump and magically routes it so the water always flows out in one direction. Now we have a stream, not a slosh.
B. NTC Thermistor (5D-11)
- Description: The black disc component.
- Function: Limits "Inrush Current" (prevents sparks when plugging in a dead battery).
- The Analogy: A Self-Widening Pipe. When you first turn on the water, this pipe is very narrow (high resistance). This prevents a massive "water hammer" that could burst the pipes. As the water flows and warms it up, the pipe expands to let the full flow through efficiently.
C. Supercapacitor (16V / 83F)
- Description: The large blue cylindrical energy storage unit.
- Function: Stores a massive amount of energy to run the heavy push coils.
- The Analogy: The City Water Tower. It takes a lot of pumping to fill this huge tower up. But once it is full, it can supply a massive volume of water to the city (the bus) instantly.
D. 30A Fuse
- Description: A safety device that melts if current gets too high.
- Function: Protects the system from dangerous over-current.
- The Analogy: A Designed Weak Link. If the pressure gets dangerously high, this thin section of pipe bursts safely, stopping the flow immediately before the Water Tower explodes.
E. Ideal Diode Module

- Description: A smart circuit board that acts like a one-way valve.
- Function: Allows power to leave the Supercap but prevents power from flowing back into it.
- The Analogy: A One-Way Gate. It lets water leave the tower to go to the city, but it locks shut if the city water tries to flow backward into the tower.
F. Low Voltage Disconnect (LVD)
- Description: A smart switch that monitors voltage.
- Function: Disconnects the load if the battery/cap gets too low (e.g., below 11V).
- The Analogy: A Smart Sluice Gate. It keeps the gate locked shut until the Water Tower has enough pressure (e.g., 12 PSI). It prevents the city from draining the tower completely dry, which would crash the system.

Output: To +BUS (The City Main).

4. Path B: The Logic Tap (Bottom Path)

This path is the "Fast Lane." It is designed to wake up the Brain (Arduino) instantly, without waiting for the big Water Tower to fill.

A. Logic Bridge (Small Rectifier)
- Description: A smaller version of the main bridge.
- Function: Converts the AC side-stream into DC.
- The Analogy: Small Check Valves. Just like the big ones above, these ensure our little side-stream flows in only one direction.
B. TVS Diode (P6KE33CA)
- Description: A fast-acting clamping diode.
- Function: Protects against sudden voltage spikes above 33V.
- The Analogy: An Emergency Pressure Relief Valve. Normally, it stays closed. But if the pump sends a sudden "shockwave" (over 33 PSI), this valve blasts open instantly to dump the excess pressure. It saves the delicate pipes downstream from bursting.
C. Resistor Series Chain (3x 100Ω)
- Description: Three resistors connected end-to-end.
- Function: Limits current and drops the voltage significantly.
- The Analogy: Long, Rough Tubing. The pump pressure is huge (30 PSI), but the Brain can only handle 5 PSI. We force the water through a long, narrow, rough tube. The friction slows the water down, dropping the pressure from "Fire Hose" levels to gentle "Garden Hose" levels. We use three sections so no single section gets too hot from the friction.

D. Zener Diode (5.1V)
- Description: A voltage-regulating diode.
- Function: Clamps the voltage at exactly 5.1V.
- The Analogy: An Overflow Pipe. Imagine an open vertical pipe cut exactly at 5.1 inches high.
- If the water level is safe (below 5.1), it flows past.
- If the water level tries to rise to 6 inches, it simply spills out the top of this pipe onto the floor.
- This guarantees the pressure going to the Brain never exceeds 5.1 PSI.
E. Capacitors (0.1µF & 10µF)
- Description: Small energy storage buckets.
- Function: Filters out noise and smooths the voltage.
- The Analogy: Buffer Buckets. The water coming out of the rough tubing might be sputtering or dripping. We put small buckets here to catch the drips. They provide a smooth, steady pour into the final filter.
F. BQ25570 Module
- Description: A high-efficiency energy harvester and regulator.
- Function: Takes the variable input and outputs a perfect 5.0V.
- The Analogy: The Brita Filter. It takes the pre-treated water we just cleaned up and polishes it to a perfect, steady 5.0V supply for the delicate Arduino brain.

Output: To 5V Logic (Powers the Arduino and Hall Sensors).

- 8.2 Cold‑start chain (Column D harvest):

Figure 8-2 — Cold-Start Power Chain (No Battery Required)

Figure 8-2 shows how the system starts with no battery. A hand flick makes the generator coils produce alternating current. The bridge rectifier changes that into direct current so it can charge the supercapacitor.. The NTC inrush limiter (NTC = a resistor that starts high and then drops) prevents a big surge of current into an empty supercapacitor. The ideal diode stops +BUS from dumping back into the supercapacitor. The low-voltage disconnect keeps the system from turning on too early and then collapsing. At the same time, a separate low-voltage tap powers the Arduino safely through a 5.1 V clamp (clamp = prevents voltage going above a safe limit) and the BQ25570 energy harvester (energy harvester = chip that boosts low input voltage to a stable 5 V). Once +BUS is stable, the normal 5 V buck converter powers the logic rail.

- D‑column coils in series‑aiding → KBPC3510 bridge → NTC 5D‑11 → 16 V / 83 F supercap → Ideal‑diode module (50 A, 80 V) → LVD → +BUS.
- Why: Hand‑flick creates AC on D; bridge makes DC; NTC soft‑charges the cap; ideal‑diode lets energy flow to the bus but blocks back‑flow; LVD only connects the cap to +BUS when it’s high enough.
- 8.2 Logic power at startup

First hand‑flick induces voltage on the Column‑D series string; its bridge rectifier

produces DC.

IMPORTANT: The BQ25570 input (VIN_DC) must stay within its absolute maximum (≈5.5 V). Since the full Column D voltage can exceed 30 V at high speed, you must not connect the BQ25570 directly to the bridge output. Instead, feed the BQ25570 from a Protected Logic Tap connected in parallel to the Column D AC lines.

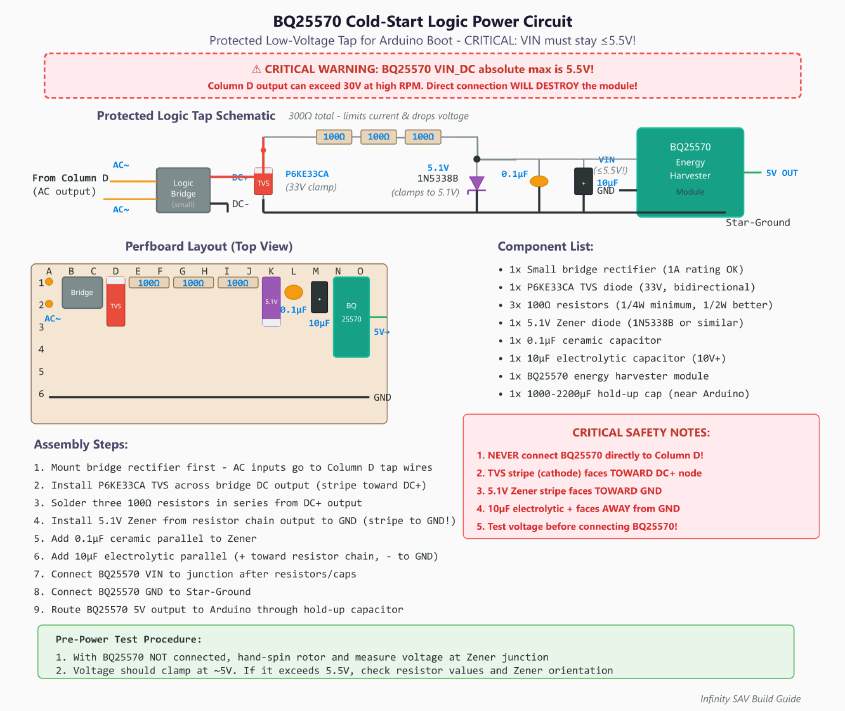
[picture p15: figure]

Figure 8-3: Protected Logic Tap Assembly (BQ25570 Protection)

CRITICAL SAFETY CIRCUIT: You must build this "Firewall" before connecting the BQ25570 Energy Harvester.

- Why: The main harvest voltage can spike to 30V+, but the BQ25570 chip will die instantly if it sees more than 5.5V.
- How it works:
1. The Bridge: Takes AC from the coil tap and turns it into DC.
2. The Resistors (3x 100Ω): These limit the current and slow the voltage rise so the clamp diodes can safely protect the circuit.

3. The Zener (5.1V): Acts as an emergency overflow valve. It forces the voltage to stay at 5.1V, keeping the BQ chip safe.
- Test First: Before plugging in the BQ module, spin the rotor by hand and measure the voltage at the "OUT" pads. It should never exceed 5.2V.

8.3 Logic Power Protection Assembly (The "Firewall")
Objective: Build the protection circuit that allows the generator to self-start without destroying the sensitive energy harvester.

The Problem: The generator produces high-voltage spikes (30V+). The BQ25570 chip explodes at 5.5V.

The Solution: This board acts as a "Firewall." It clamps the voltage to a safe 5.1V before it reaches the brain.

Critical Rule: The "Flip"
- Top View (Placement): You look down at the components. The AC (~) pins are on the LEFT.
- Bottom View (Soldering): You flip the board over. The AC (~) pins appear on the RIGHT.
- Safety: Always trust the symbols printed on the Bridge Rectifier body (+, -, ~), regardless of left/right orientation.
Step 1: Component Placement (Top View)
Use Figure 8-4a to insert your components. Do not solder yet.
- Bridge Rectifier: Align the printed symbols. + goes toward the resistors. ~ goes toward the AC input wires.
- TVS Diode (P6KE33CA): This part is Bidirectional. It has no polarity band; you can install it either way.
- Zener Diode (1N5338B): The Stripe (Cathode) must face UP (towards the resistors). This connects it to the Positive rail.
- Resistors: Leave a small air gap (2mm) under the resistors for cooling.

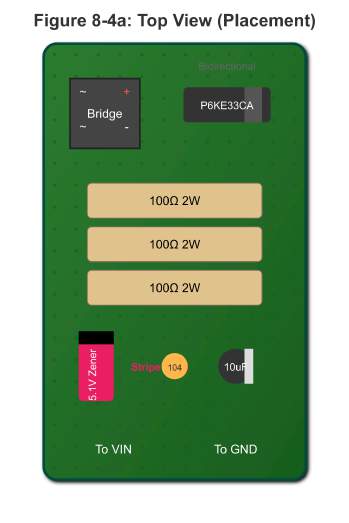
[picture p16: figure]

Figure 8-4a: Top View (Placement). Note the Zener Stripe facing the positive rail.

Step 2: Wiring & Soldering (Bottom View)
Flip the board over. Use Figure 8-4b to solder the connections. This view is MIRRORED.
- Copper (Orange Lines): This is the VIN (+) path.
- Grey (Silver Lines): This is the GND (-) path.
- Warning: Notice that the AC Inputs (#1a, #1b) are now on the RIGHT side.

Figure 8-4b: Bottom View (Mirrored Solder Map). Follow the numbered ID tags in the table below.

Step 3: Assembly Netlist (The Instructions)
Table 8-4: Step-by-Step Soldering Guide
ID | Action | Source (Compone nt Leg) | Destination (Target) | Critical Note
#1 | Solder a Wire / # b | Bridge ~ and ~ pins | To Column D Tap Wires | Use BOTH AC pins. Polarity doesn't matter.

#2 | Solder Bridg e | Bridge DC+ (Marked +) | Copper Rail (VIN) | Verify Symbol on Bridge Body.

#3 | Solder Bridg e | Bridge DC-(Marked -) | Grey Rail (GND) | Verify Symbol on Bridge Body.

#4 | Solder Chain | Resistor Legs | R1 $\to$ R2 $\to$ R3 | Connect the 3 resistors in a straight line.

#5 | Create Rail | Copper Wire (Bare) | Across R3, Zener, Caps, Output | This is the "Clean 5.1V" Junction Bar.

#6 | Orientati on | ⚠ CHECK ZENER | Stripe $\to$ Junction Bar (#5) | CRITICAL: Stripe (Cathode) $\to$ Positive (#5).

#7 | Create Rail | Bare Wire (GND Rail) | Down the Right Side | Connects Bridge -and Zener Anode.

#8 | Solder Wire | Red Wire (Out) | From Pad #8 (on Copper Rail) | To BQ25570 VIN_DC.

#9 | Solder Wire | Black Wire (Out) | From Pad #9 (on Grey Rail) | To Star Ground.

Step 4: System Logic & Troubleshooting
How it works:
1. Harvest: The Bridge converts raw AC into DC.
2. Surge Protection: The TVS Diode clamps massive spikes (up to 33V).
3. Current Limiting: The 3 resistors (300Ω total) limit current and drop voltage.
4. Voltage Clamp: The Zener Diode forces the output to stay at 5.1V.
5. Bootstrap: The BQ25570 takes this safe energy and boosts it to 5V to wake up the Arduino.

Troubleshooting:

- System won't boot: Check Step #6. If the Zener is backwards, it shorts the power to ground.
- No Voltage at Output: Check Step #1. Did you connect both AC wires?
- Resistors overheating: Check if the TVS diode is bridging/shorting the rails at Step #2/#3.
- Note: Optional DC/DC for drivers: A 12 V buck for the TC4427 drivers (if you choose to drive row MOSFETs at 10–12 V). Fuse 10 A.

8.5 The Master Power Map (System Architecture)

Figure 8-5 (below) is the "Subway Map" of your generator. It shows how the different voltage rails (Harvest, Logic, and Main Bus) interact without blowing each other up.

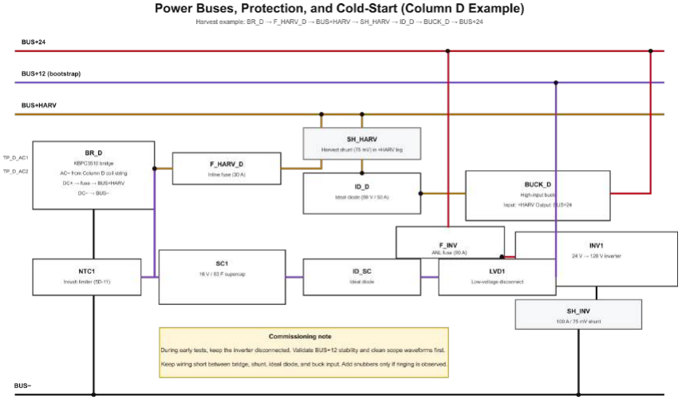
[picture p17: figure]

Figure 8-5: Master Power Schematic. This shows the logical flow of energy from Coils to the Main Bus.

How to Read This Map:

1. The Three "Subway Lines" (Voltage Rails):
- Brown Line (Harvest): This is raw, wild energy coming straight from the coils/bridges. It is variable and unregulated.
- Red Line (+24V Bus): This is the "City Main." It is the stable, high-power rail that feeds the Inverter and the Push Coils.
- Purple Line (+12V Bus): This is a specialized local rail created by the Buck Converter (BUCK_D) to power the Gate Drivers (TC4427).
2. The "Traffic Cops" (Ideal Diodes):
- Look at ID_D and ID_SC. These are Ideal Diodes.
- Their Job: They act like one-way check valves. They allow the Harvest (ID_D) and the Supercap (ID_SC) to both pour water into the main tank (+BUS), but they prevent the water from flowing backwards into the wrong pipe.
3. The Safety Layer (Fuses & Protection):
- Fuses (F_...): Notice that every major block has a fuse before it joins the main line. If the Inverter shorts out, F_INV blows to save the Supercap.
- Inrush Limiter (NTC1): This is the "Soft Start" valve. It sits between the Bridge and the Supercap. Without it, plugging in the empty Supercap would be like opening a floodgate—it would spark and melt the wires.

Student Note: Physical vs. Logical Wiring

- Shunt Location: This diagram shows the Harvest Shunt (SH_HARV) on the Positive line (High-Side).
- WARNING: Most student meters (like Bayite) require shunts on the Negative line (Low-Side) to work correctly.
- Rule: Follow this diagram for Logic (where power goes), but follow Section 11 (Meters) for the specific wiring of your black shunt wires.

## 9) Switching: how does one coil get a push?

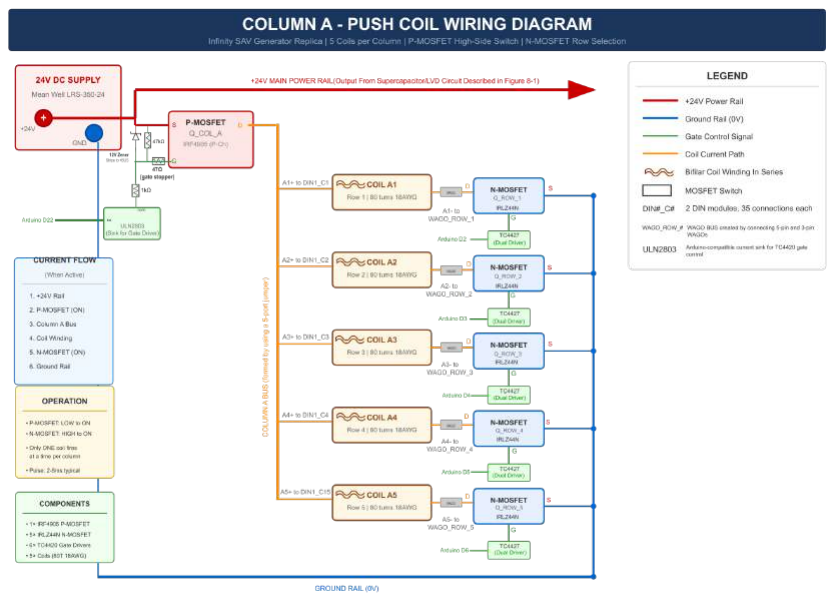
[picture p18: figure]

Figure 9-1. Column A - Push Coil Wiring Diagram. (Also applies to any push column like F)

The Push Coil System Analogy: Precision Sniping (Self-Powered).

The Analogy: Imagine your generator is an Off-Grid Building (Column A). You rely entirely on your own rooftop Water Tower (Supercapacitor) to run the machinery. You must efficiently spray water (electricity) into one specific turbine at a time to keep the generator spinning, which in turn refills your tower.

1. The Source (Far Left): The Rooftop Water Tower
- Component: +24V MAIN POWER RAIL (Red Line)
- Description: Fed directly from the Supercapacitor/LVD Circuit (Harvest System).
- The Analogy: Your Private Water Tower.
- Startup: At first, the tower is empty. You spin the rotor by hand ("hand-flick") to pump the first few gallons up into the tank.
- Running: Once the tower has enough pressure (Voltage), the LVD valve opens and pressurizes this red pipe. Now, the building runs on its own stored water.
2. The High-Side Switch (Top Center): The Building Master Valve
- Component: P-MOSFET (IRF4905) + Gate Network
- Function: Controls power for the entire column. If this is OFF, the building is dry.
- The Analogy: The Building Master Valve.
- Even though the Tower is pressurizing the pipe, this valve stays shut tight (held by the 47kΩ Spring). Water cannot enter the floors until we pull the lever.

Sub-Component: ULN2803 (The Valve Operator)

- Analogy: The Pilot Valve. The Arduino is too weak to pull the heavy Master Valve lever. It whispers to the ULN2803, which uses its strength to pull the lever down, letting water rush into the building.

Sub-Component: Zener (12V) + 1kΩ Resistor (The Safety Chain)

- Analogy: The Safety Chain. The lever is fragile. If you pull it all the way down (24 inches), it snaps. This chain stops the lever at exactly 12 inches (12V), letting the valve open fully without breaking the handle.

Sub-Component: 47Ω Resistor (The Gate Stopper)

- Description: The tiny resistor right at the MOSFET Gate pin.
- Analogy: The Vibration Damper. When the Pilot Valve slams the lever down, the lever might bounce or vibrate ("ring"). This small rubber washer absorbs the vibration so the valve opens smoothly and stays cool.
3. The Column Bus (Vertical Orange Line): The Riser Pipe
- Component: Column A Bus
- The Analogy: The Vertical Riser Pipe.
- When the Master Valve opens, water fills this vertical pipe. Every floor (Coils A1–A5) has pressurized water waiting at the inlet, but nothing flows yet because the drains are closed.
4. The Loads (Center): The Water Wheels

- Components: Coils A1–A5 (Bifilar Series-Aiding)
- The Analogy: Turbines (Water Wheels).
- Water pushes against the wheel, trying to get through. But water can't spin the wheel if the pipe after it is blocked. It sits there, holding potential energy.
5. The Low-Side Switches (Right): The Floor Drain Valves
- Components: N-MOSFETs (IRLZ44N) + TC4427 Drivers
- The Analogy: Individual Floor Drains (The Trigger).
- This is the moment of action.
- Arduino signals the Floor 3 Drain to SLAM OPEN (via the TC4427 Hydraulic Booster).
- Water rushes from the Tower, down the Riser, through Turbine 3, and out the drain.
- Result: The rotor gets a magnetic kick! Turbines 1, 2, 4, and 5 stay dry.
6. The Return (Bottom Blue Line): Recirculation
- Component: Ground Rail (0V)
- The Analogy: The Return Pipe.
- The water drains back to the negative side of the capacitor bank to complete the loop.
7. The Protection: Flyback Management (Crucial)
- Components: MUR460 Diode + TVS Diode (Located at the P-MOSFET).
- The Analogy: The Water Hammer Arrestor.
- The Danger: When you slam the Master Valve shut at the end of a pulse, the rushing water (electricity) crashes into the closed valve. This shockwave ("Flyback") can burst the pipes.
- The Fix:
■ The MUR460 is a recirculation loop that guides this shockwave back into the tank safely.
■ The TVS is an emergency airbag that absorbs any leftover spike.
- Student Note: Without these, your Master Valve (P-MOSFET) will eventually crack from the pressure shocks.

Summary of the Pulse

1. Flick: Hand-spin pumps water to the Tower.
2. Ready: Tower fills. Arduino wakes up.
3. Fire:
- Arduino opens Master Valve (P-FET). Pipes pressurize.
- Arduino slams open Floor 3 Drain (N-FET).
4. Action: Water blasts through Coil A3. Rotor spins.

5. Safety: Valves slam shut. The Arrestor (MUR460) catches the shockwave.
6. Refill: The faster rotor pumps more water back into the Tower.

9.1 High‑side column switch (2 columns: A & F)

Figure 9-1a: P-FET High-Side Gate Network (IRF4905)

In the main Push Coil Diagram, we showed the P-MOSFET (IRF4905) acting as the "Building Master Valve" that controls all power to Column A.

However, you cannot just wire a switch directly to a high-pressure line. If you pull the lever too hard, it snaps. If you close it too fast, the pipes burst. This detailed schematic shows the Safety Mechanism required to operate that Master Valve safely.

1. The Default State: The "Safety Spring" (OFF)
- Component: 47 kΩ Pull-Up Resistor.
- Location: Connected between the Gate (Control Lever) and the Source (+BUS).
- The Analogy: The Tension Spring.
- This spring holds the valve lever tight against the high-pressure line ($V_{GS} = 0$).
- Why: It ensures the Master Valve stays locked shut by default. If the Arduino resets or loses power, this spring snaps the valve closed so the coil never fires accidentally.

2. The Turn-ON Sequence: Pulling the Lever
To open the valve, we must pull the Gate lever down (lower voltage than the Source).
- The Muscle (ULN2803A):
- Analogy: The Pilot Valve. The Arduino is too weak to pull the heavy Master Valve lever itself. It signals the ULN2803A, which uses its strength to pull the lever down towards the ground.
- The Safety Chain (12 V Zener Diode):
- Analogy: The Stop Chain.
- The Danger: The IRF4905's internal lever is fragile. If you pull it all the way down to the floor (24 V difference), it snaps (Gate Oxide Rupture).
- The Fix: The Zener Diode acts like a chain that catches the lever after exactly 12 inches (12 V). It allows the valve to open fully but prevents the lever from being pulled to the breaking point.
- The Current Limiter (1 kΩ Series Resistor):
- Analogy: The Shock Absorber.
- Critical Physics: When the "Safety Chain" (Zener) catches the lever, there is a sudden jerk of tension. Without this resistor, the full force of the 24 V bus would rush through the Zener, burning it out instantly. This resistor limits the tension to a safe level (a few milliamps).
- The Damper (47 Ω Gate Stopper):
- Analogy: The Rubber Washer.
- Location: Right at the MOSFET Gate pin.
- Why: When the Pilot Valve slams the lever, it tends to vibrate or "ring" like a bell. This small resistor absorbs the vibration, ensuring the valve opens smoothly without overheating.
3. The Turn-OFF: Managing "Water Hammer"
- Components: MUR460 Diode and TVS (1.5KE33A).
- Analogy: Water Hammer Arrestors.
- The Danger: When you slam the Master Valve shut after a pulse, the electricity (water) rushing through the column crashes into the closed valve. This creates a massive pressure spike ("Flyback") that can crack the pipe.
- The Fix:
■ The MUR460 recirculates this shockwave back into the supply tank safely.
■ The TVS acts as an emergency airbag to absorb any leftover spikes.

Summary for Assembly (The "Blueprint")
When building the P-MOSFET Module, follow these rules to match the diagram:
1. Placement: Mount the IRF4905 on a heatsink bar.
2. Connections:
- Source: Connects to +24V BUS.

- Drain: Connects to the Column DIN Rail.
3. The Gate Network (Soldered to the MOSFET):
- 47 kΩ: Connects Gate $\to$ Source (The Spring).
- 12 V Zener: Connects Gate $\to$ Source (Stripe touches Source).
- 47 Ω: Connects directly to the Gate pin (The Damper).
- 1 kΩ: Connects between the Gate Network and the ULN2803 driver (The Limiter). Do not omit this.
4. Logic:
- To Fire: Arduino drives ULN input HIGH. ULN pulls the gate LOW. Valve Opens.
- To Stop: Arduino drives ULN input LOW. Resistor pulls gate HIGH. Valve Closes.

In more technical language, this circuit controls the flow of power from the +BUS into the top of the coil. We use a P-channel MOSFET (IRF4905) here because it is designed to switch the high-voltage (positive) side of the line.

### 1. The Default State (Safety OFF)

Component: 47 kΩ Pull-Up Resistor.

Role: Connects the Gate to the Source (+BUS).

Why: By keeping the Gate voltage equal to the Source voltage ($V_{GS} = 0$), the MOSFET stays tightly closed (OFF). This ensures the coil never fires accidentally if the Arduino resets.

### 2. The Turn-ON Sequence

To open the valve, we must pull the Gate voltage lower than the Source.

The Driver (ULN2803A): The Arduino cannot handle 24 V directly. It signals the ULN2803A, which acts as a "sink" (connecting the circuit to Ground).

The Protection (12 V Zener Diode):

The Danger: The IRF4905 gate insulation ruptures if the voltage difference exceeds 20 V. If your +BUS is 24 V and you pull the gate to 0 V, that 24 V difference destroys the chip.

The Fix: The Zener Diode "clamps" the difference to exactly 12 V—perfect for turning the switch ON safely.

The Current Limiter (1 kΩ – 2.2 kΩ Series Resistor):

Critical Physics: When the Zener activates, it creates a short circuit from +BUS through the driver. Without this resistor, massive current would flow, burning out the Zener instantly. This resistor limits that current to a safe level (a few milliamps) while allowing the gate to trigger.

### 3. Flyback Management (The Turn-OFF)

Components: MUR460 Diode and TVS (1.5KE33A).

Why: When the switch turns OFF, the coil acts like a flywheel—it tries to keep the current moving, creating a massive high-voltage spike backwards. The MUR460 recycles this energy to the bus, and the TVS absorbs any remaining spike to protect the MOSFET.

In Summary:

- P‑MOSFET IRF4905 per column on a heatsink bar.
- Source → +BUS, Drain → that column’s DIN rail.
Gate network per device:
■ 10–47 kΩ Gate→+BUS (47 kΩ default; 10 kΩ gives stronger pull-up/noise immunity).

■ Gate resistors: (a) Gate stopper 22–47 Ω placed close to the MOSFET gate, and
(b) a series CURRENT‑LIMIT resistor 1 kΩ to 2.2 kΩ between the gate node and the ULN2803A sink (prevents Zener/ULN over‑current when +BUS > Zener voltage).

■ 12 V Zener Gate→Source (cathode at Source, anode at Gate) to limit |VGS|.

■ Why the extra series resistor matters: When the ULN2803A pulls the gate low, the Zener conducts to clamp VGS. Without a current‑limit resistor, a 12–24 V bus can force very high clamp current. Use 1 kΩ–2.2 kΩ so the clamp current stays in the few‑milliamp range.

- How it turns ON: A ULN2803A channel sinks the gate to ground. The ULN’s input is driven from the Arduino (or a PCA9685). The ULN can only pull down; the 10 kΩ resistor pulls the gate up when we want it OFF.
- Keep +BUS ≤ 50 V for ULN2803A; above that, use a discrete 2N2222 sink stage.

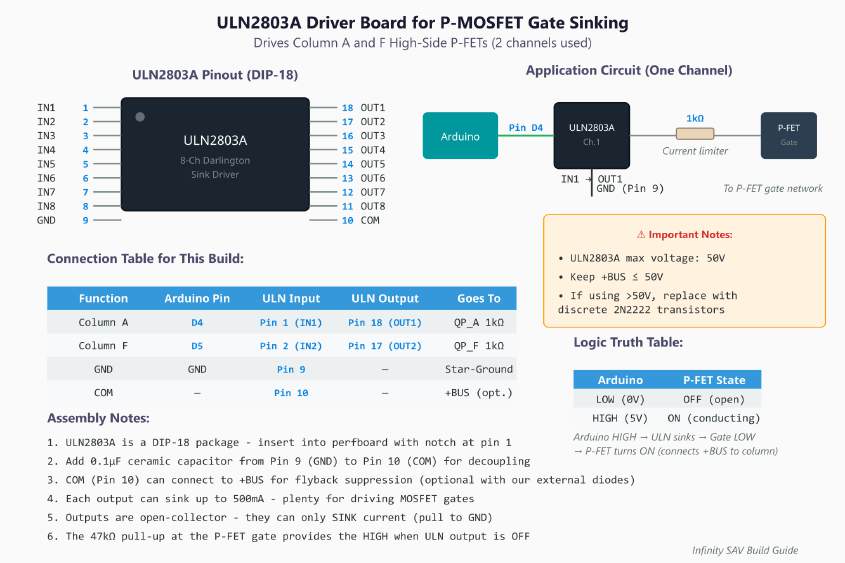
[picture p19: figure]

Figure 9-1b: ULN2803A Driver Board Assembly (The "Pilot Valve")

The High-Side Trigger: This board connects the weak 5V signal from the Arduino to the powerful P-MOSFET switches.

- Mounting: Place this on the Door near the Arduino Mega.
- Wiring: Connect Arduino Pin D4 to Input 1, and Pin D5 to Input 2. The outputs go to the P-FET gate networks on the backplate.
- Safety: The Ground pin (Pin 9) connects to the system Star-Ground. This completes the circuit that allows the chip to "pull down" the P-FET gates.

9.1c Sub-Component: ULN2803A Driver Board (4×6 cm)
Objective: Build the interface that allows the delicate Arduino (5V) to switch heavy-duty Relays or Solenoids (12V/24V).
The "Flip" Rule:
- Top View (Placement): The Chip Notch faces UP. Pin 1 is Top-Left.
- Bottom View (Soldering): MIRRORED. Pin 9 (GND) is on the Bottom-Right.
- Safety: Never power this board until you confirm Pin 9 is GND and Pin 10 is COM (+V). Reversing these blows the chip instantly.

1. Component Placement (Top View)
Use Figure 9-1c(Top) to insert your components.
- Socket: Always solder an 18-Pin DIP Socket first. Do not solder the chip directly.
- Orientation: The Notch on the socket/chip must face UP.
- Inputs (Left): Header for signals coming from Arduino.
- Outputs (Right): Header for signals going to Relays/Coils.

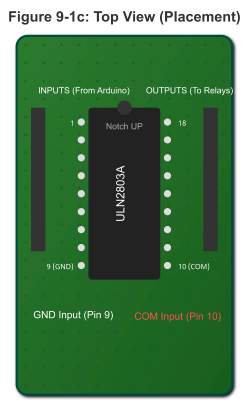
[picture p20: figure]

Figure 9-1c (Top): Component Placement. Ensure the Chip Notch faces UP.

2. Wiring & Soldering (Bottom View)
Flip the board. This view is MIRRORED.
- Pin 9 (Bottom Right): Must go to GND Rail (Grey).
- Pin 10 (Bottom Left): Must go to COM Rail (Copper).
- Inputs: Connect to the Right side pins (1–8).
- Outputs: Connect from the Left side pins (18–11).

Figure 9-1c (Bottom): Mirrored Solder Map. Critical: Pin 9 is GND, Pin 10 is COM.

3. Assembly Netlist (The Instructions)
Table 9-1c: Step-by-Step Soldering Guide
ID | Action | Source (Component Leg) | Destination (Target) | Critical Note
#1 | Solder GND | Pin 9 (Bottom Right) | To Grey GND Rail | CRITICAL: Pin 9 must go to Ground.

#2 | Solder COM | Pin 10 (Bottom Left) | To Copper COM Rail | Connects to Relay Voltage (+12V or +24V).

#3 | Solder Inputs | Input Header (Right) | To Pins 1, 2... (Right Side) | From Arduino (5V Logic).

#4 Solder Outputs

Output Header
(Left)

From Pins 18,
17... (Left Side)

To Relay Coil
Negatives
(Switched Ground).
4. Usage & Safety Note
- How it Works: When Arduino sends HIGH to Pin 1, the ULN2803A connects Pin 18 to GND. This completes the circuit and turns on your relay.
- The COM Pin (Pin 10): This pin connects to internal "Flyback Diodes." You must connect the COM Rail to the Positive Voltage of your relays (e.g., +12V or +24V).
- WARNING: Do NOT connect COM to 5V. It must match the high-voltage supply of the load you are switching.

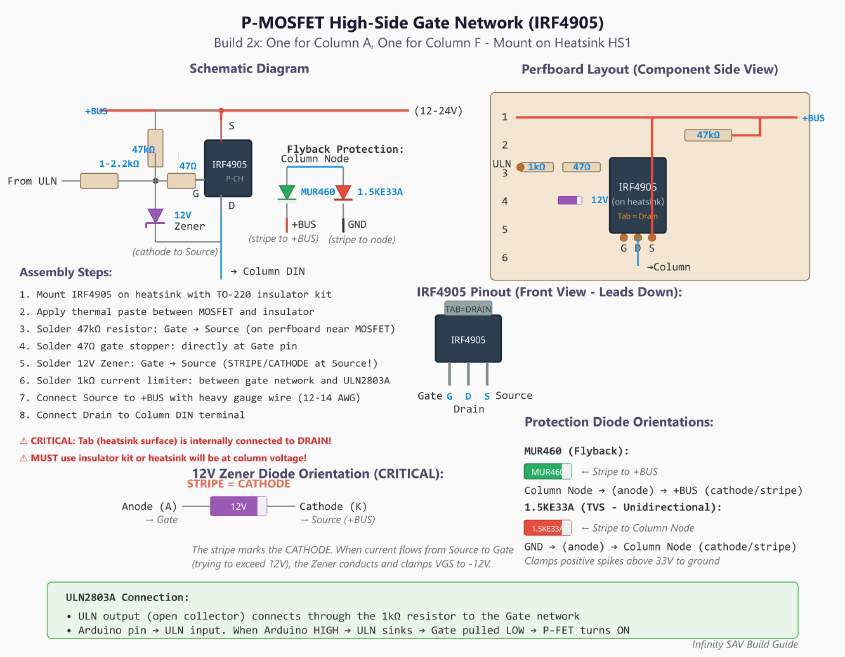
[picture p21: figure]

Figure 9-1d: P-MOSFET Gate Safety Network (Mounts on Heatsink HS1)

The "Master Valve" Safety Circuit: You cannot wire the ULN2803 directly to the P-MOSFET. You must solder these protection parts directly onto the MOSFET legs or a small board right next to it.

- 12V Zener: Prevents the gate voltage from dropping too low and rupturing the chip. Stripe must face the Source (+24V) pin.
- 1kΩ Resistor: Limits the current so the Zener doesn't burn out when it activates.
- 47kΩ Resistor: The "Return Spring" that keeps the valve closed (OFF) if the Arduino is disconnected.

9.2 Low‑side row selector (5 rows: 1…5)

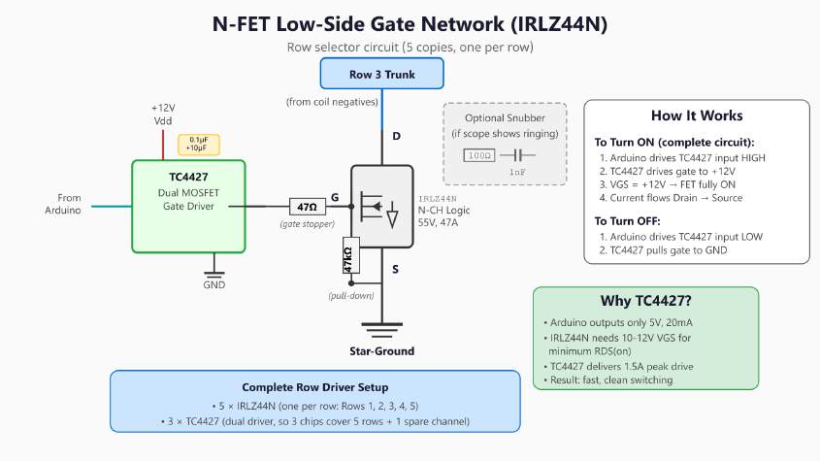
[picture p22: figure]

Figure 9-2a — N-FET Low-Side Gate Network

Deep Dive: Building the "Floor Drain Trigger" (N-FET Low-Side Switch)

In the main Push Coil Diagram, we showed the N-MOSFET (IRLZ44N) as the "Floor Drain" at the bottom of each row.

- The Challenge: The Arduino is like a weak manager. It can whisper a command, but it doesn't have the muscle to slam open a heavy industrial valve (the MOSFET) instantly. If the valve opens slowly ("creaks" open), the rushing water (current) creates friction and burns the valve up.

- The Solution: We need a Hydraulic Booster (TC4427).
1. The Muscle (TC4427 Gate Driver)
- Analogy: The Hydraulic Ram.
- The Problem: The Arduino (Manager) only has 5V of "strength" and very weak arms (low current). It opens the valve too slowly.
- The Fix: The TC4427 is a powerful hydraulic ram connected to a separate 12V supply. When the Arduino whispers "Go," the TC4427 uses that 12V muscle to SLAM the valve lever fully open in nanoseconds.
- Result: The valve goes from "Closed" to "Wide Open" instantly, skipping the dangerous "half-open" zone where heat is generated.
2. Decoupling Capacitors (0.1 µF + 10 µF)
- Analogy: The Compressed Air Tanks.
- Why: When the Hydraulic Ram (TC4427) kicks, it needs a massive gulp of energy instantly. If it has to pull that energy through long wires from the main supply, it will choke/stutter.
- The Fix: We place small tanks (Capacitors) right next to the Ram. They hold a "shot" of energy ready to go, ensuring the kick is powerful and immediate.
3. Stability Control
- Gate Resistor (47 Ω):
- Analogy: The Shock Absorber. Just like with the Master Valve, slamming the drain open too fast can cause vibration ("ringing"). This resistor dampens the shock just enough to keep it smooth.
- Safety Pull-Down (47 kΩ):
- Analogy: The Return Spring.
- Why: If the power goes out or the Arduino reboots, the Ram goes limp. We don't want the drain to float open accidentally. This spring ensures that if nobody is holding the lever, it snaps shut (Safe State).
4. The Protection (9.3 High-Speed Safety)
- Note: These parts are physically located near the P-FET (Top of Column) but work with the N-FET to protect the whole line.
- MUR460 (Flyback Diode):
- Analogy: The Recirculation Loop. When you slam the drain shut, the water in the riser tries to crash backward. This pipe guides that crash safely back to the tank.
- Location: Connected from the Column Node to +BUS.
- TVS Diode (1.5KE33A):
- Analogy: The Emergency Airbag. Absorbs any pressure spikes that the

Recirculation Loop misses.
- Location: Connected from the Column Node to Ground.

Summary for Assembly

You are building the "Trigger Module" for each row:

1. The MOSFET: IRLZ44N (Logic Level N-FET).
- Drain: Connects to the Bottom of the Coil (Row Trunk).
- Source: Connects to Star Ground.
2. The Driver: TC4427 (Dual Driver).
- Input: From Arduino Pin.
- Output: To MOSFET Gate (through 47 Ω resistor).
- Power: Needs +12V (NOT 5V, NOT 24V).
3. The Safety:
- 47 kΩ Resistor: Gate to Ground.
- Capacitors: Close to the TC4427 chip.

How it connects to the Big Picture:

- Step 1: P-FET (Master Valve) Pressurizes the Column.
- Step 2: N-FET (Floor Drain) Snaps open to fire the specific coil.
- Step 3: TC4427 (Muscle) Ensures the snap happens fast enough to stay cool.

In more technical language, this circuit connects the bottom of the coil to Star-Ground, completing the loop. We use an N-channel MOSFET (IRLZ44N) here because N-FETs are efficient and run cool.

### 1. The Muscle (TC4427 Gate Driver)

Why not use the Arduino directly? The Arduino only outputs 5 V and very weak current. A MOSFET Gate acts like a capacitor (a bucket) that needs to be filled with electrons instantly to turn ON. If you fill it slowly (using just the Arduino), the MOSFET spends too much time "half-open," generating dangerous heat.

The Solution: The TC4427 takes the weak 5 V command and blasts a strong 12 V signal into the MOSFET. This snaps the switch fully ON instantly, keeping it cool.

Decoupling Capacitors (0.1 µF + 10 µF): These are placed right next to the Driver. They act like local "energy tanks," providing the sudden gulp of power the driver needs to snap the gate open without dipping the voltage rail.

### 2. Stability Control

Gate Resistor (47 Ω): Placed between the Driver and the MOSFET. It slows down the switching speed just enough to prevent "ringing" (electronic echoing) without causing heat.

Safety Pull-Down (47 kΩ): Connects Gate to Ground. If the Driver loses power or the Arduino is rebooting, this resistor ensures the Gate bleeds off any charge and stays OFF.

In Summary:

- N‑MOSFET IRLZ44N per row.
- Drain → that row’s negative trunk, Source → Star‑Ground.
- Gate from TC4427 driver through 22–68 Ω; add 10–100 kΩ Gate→Source as a pull‑down.
- Decouple each TC4427: 0.1 µF + 10 µF at its Vdd pins.

Figure 9-2b: N-MOSFET & TC4427 Driver Assembly (Mounts on Heatsink HS3)

The "Muscle" Board (Row Drivers): This circuit slams the row switches (IRLZ44N) open and closed instantly to prevent heat.

- Adapter Required: The TC4427 chip is tiny (Surface Mount). You must solder it to the DIP-8 Adapter Board before you can use it. Use flux and a

magnifier!
- Placement: Mount this board on the Backplate, right next to the Row MOSFETs (Heatsink HS3).
- Distance Rule: The gate wire between this board and the MOSFET must be as short as possible (target <10 cm). Long wires will cause oscillation.
- Capacitors: The 0.1µF and 10µF capacitors act as "Air Tanks" for the driver. They must be soldered as close to the chip as possible.

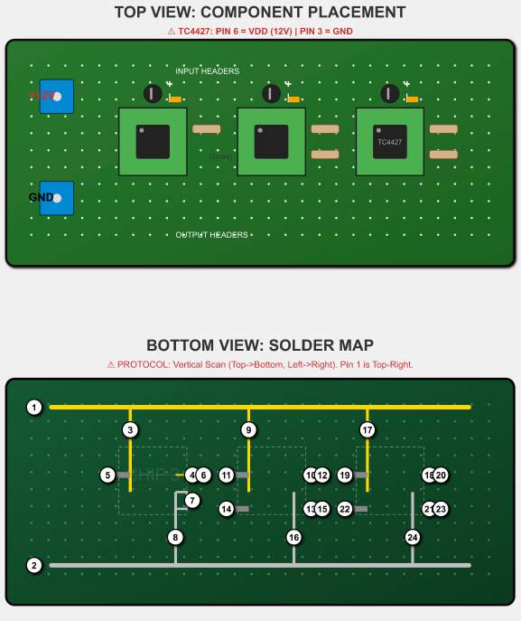
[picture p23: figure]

Figure 9-2c: N-FET Gate Driver Perfboard Layout (3x7 cm)

Student Build Guide: N-FET Driver Board Assembly

Standard: IPC Class 2 Reliability Objective: Build a high-speed, high-current driver board capable of surviving vibration and thermal stress. Reference Artifact: Figure 9-2c (Double-View Solder Map)

Phase 1: The "Mise-en-place" (Preparation)

Professional Standard: 90% of soldering defects are caused by oxidation or dirt.

1. Clean the Board: Scrub the copper side of the perfboard with a Scotch-Brite pad or steel wool until it shines bright gold/pink. Wipe with Isopropyl Alcohol (99%). Do not touch the copper with bare fingers after this.
2. Flux is Life: If the solder won't stick, you aren't using enough flux. Use a flux pen on the pads before applying heat.
3. The "Third Hand": Secure the board in a vise or "helping hands." You cannot hold the board and solder professionally at the same time.

Phase 2: Surface Mount First (The Hard Part)

Logic: Always solder the lowest-profile components first. If you solder the tall headers first, you can't flip the board flat to do the chips.

Step 1: Mount the TC4427 Chips to Adapters
- Orientation Rule: The Dot on the TC4427 chip marks Pin 1. All pin numbers in this guide assume the chip is oriented exactly as shown in Figure 9-2c (Top View).
- Goal: Solder the tiny SOIC-8 chips onto the Green DIP-8 Adapter boards.
- Technique: "Tack and Drag."
1. Tin one pad on the green adapter.
2. Slide the chip in with tweezers (Align the Dot with the Pin 1 mark).
3. Re-heat the tinned pad to lock the chip in place.
4. Solder the remaining 7 pins.
5. Inspect: Use a magnifying glass to ensure no solder bridges connect two adjacent legs.

Phase 3: The Power Grid (Creating the Rails)

Logic: High-current paths must be solid copper to handle the 12V load without voltage sag.

Step 2: Create the Bus Bars (IDs #1 & #2)
- Material: Strip 15cm of Solid Core 18 AWG Wire.
- Action: Lay the bare wire along the Top Row and Bottom Row as shown in the Solder Map.
- Execution:
- ID #1 (+12V In): Solder the Red Terminal Block. Run the bare wire from this block across the entire top row. Solder it to the perfboard every 4-5 holes to secure it.
- ID #2 (GND In): Solder the Black Terminal Block. Run the bare wire across the bottom row. Secure it.

Phase 4: Component Population & The "24-Point" Connection

⚠️ IMPORTANT DESIGN CHANGES (Don't Panic!) You may notice differences if you compare this to the theoretical schematic (Figure 9-2a). Follow these Hardware Updates:

- Resistors: We are using 22Ω (Red-Red-Black) instead of 47Ω. This creates faster switching speeds for our magnetic application.
- Pull-Down Resistors: The 47kΩ resistors shown in early concepts are NOT INSTALLED. The TC4427 chip handles this function internally, so these are redundant.

Instructions: Insert components from the Top Side. Flip over. Solder connections on the Bottom Side using this specific checklist.

A. Power & Decoupling (The Energy Tank)

Technique: The "3-Point Bridge". You are joining the Chip Pin, the Capacitor Leg, and the Power Rail into one solid joint.

- [ ] ID #17 (Chip 1 +): Bridge Pin 6 + Capacitor(+) to the Top Rail (+12V).
- [ ] ID #24 (Chip 1 -): Bridge Pin 3 + Capacitor(-) to the Bottom Rail (GND).
- [ ] ID #9 (Chip 2 +): Bridge Pin 6 + Capacitor(+) to the Top Rail.
- [ ] ID #16 (Chip 2 -): Bridge Pin 3 + Capacitor(-) to the Bottom Rail.
- [ ] ID #3 (Chip 3 +): Bridge Pin 6 + Capacitor(+) to the Top Rail.
- [ ] ID #8 (Chip 3 -): Bridge Pin 3 + Capacitor(-) to the Bottom Rail.
B. Signal Inputs (The Brains)

Technique: Use thin insulated wire (24 AWG) for these signals to avoid shorting against the bare power rails.

- [ ] ID #18 (Row 1 In): Solder wire from Chip 1, Pin 2 to the Input Header.
- [ ] ID #21 (Row 2 In): Solder wire from Chip 1, Pin 4 to the Input Header.
- [ ] ID #10 (Row 3 In): Solder wire from Chip 2, Pin 2 to the Input Header.
- [ ] ID #13 (Row 4 In): Solder wire from Chip 2, Pin 4 to the Input Header.
- [ ] ID #4 (Row 5 In): Solder wire from Chip 3, Pin 2 to the Input Header.
- [ ] ID #7 (Safety Jumper): On Chip 3, create a solder bridge connecting Pin 4 directly to Pin 3 (GND).
- Why? This prevents the unused input from "floating" and causing unintended switching.
C. Gate Outputs (The Muscle)

Technique: Solder the resistor "inline". One leg goes to the chip, the other goes to the output header.

- [ ] ID #19 & #20 (Row 1): Solder Chip 1, Pin 7 to Resistor Leg. Solder other leg to

Output Header.
- [ ] ID #22 & #23 (Row 2): Solder Chip 1, Pin 5 to Resistor Leg. Solder other leg to Output Header.
- [ ] ID #11 & #12 (Row 3): Solder Chip 2, Pin 7 to Resistor Leg. Solder other leg to Output Header.
- [ ] ID #14 & #15 (Row 4): Solder Chip 2, Pin 5 to Resistor Leg. Solder other leg to Output Header.
- [ ] ID #5 & #6 (Row 5): Solder Chip 3, Pin 7 to Resistor Leg. Solder other leg to Output Header.

Phase 5: Professional Inspection (QC)

Pass/Fail Criteria:

1. The "Volcano" Test: Look at every joint. It should look like a shiny, concave volcano (curved in). If it looks like a ball (convex), it is a "cold joint" and will fail. Reflow it with flux.
2. The "Tug" Test: Gently tug on your power rail wires. They should not move.
3. The Beep Test:
- Setup: Set Multimeter to Continuity Mode.
- Short Check: Probe Top Rail and Bottom Rail. Silence = Pass. (Beep = Short Circuit / FAIL).
- Power Check: Probe Top Rail and Chip Pin 6. Beep = Pass.
- Ground Check: Probe Bottom Rail and Chip Pin 3. Beep = Pass.

Recommended Instructional Videos

Note: These videos are optional but highly recommended to visualize the techniques before you begin.

- Video: How to Solder SOIC Chips to Adapters (https://www.youtube.com/watch?v=8Pv4he_DtG0)
- Focus: Watch 01:40 to 05:00 for the "tack and drag" method used in Phase 2.
- Video: Creating Perfboard Solder Bridges (https://www.youtube.com/watch?v=l9Kbr8cPqOE)
- Focus: Watch 03:10. This shows exactly how to lay down the bare copper wire ○

9.3 Heatsink Mechanical Assembly (The Skeleton)

Objective: Physically mount the 5 N-Channel MOSFETs (IRLZ44N) to Heatsink HS3. Why: You cannot solder the "Floating Bus Bars" (Section 9.4) until the chips are bolted down rigidly to serve as anchors. Critical Standard: Electrical Isolation. The metal tab of the MOSFET must NOT touch the aluminum heatsink. If it touches, the entire heatsink becomes electrified, causing a massive short circuit.

1. The Layout Strategy (Spacing & Height)

We need the MOSFETs spaced widely enough to solder the protection diodes between them, but close enough to share the rigid copper bus bars.

- Vertical Position: Draw a line horizontally across the center of the heatsink face.
- Horizontal Spacing (The Grid): Mark 5 drill holes along that center line, exactly 25 mm (1 inch) apart.
- Why 25 mm? The MOSFET is ~10 mm wide. This leaves a 15 mm air gap between chips, which is the perfect space to fit the protection diodes later without shorting.
2. The "Isolation Sandwich" (Mounting)

You are building a specific stack of parts to let heat flow out while keeping electricity in.

Parts Per MOSFET:

1. IRLZ44N MOSFET.
2. Silicone Thermal Pad (Grey/Blue square) OR Mica Insulator + Thermal Paste.
3. Plastic Shoulder Washer (T-shaped washer). <-- CRITICAL PART.
4. M3 Bolt & Nut.

Step-by-Step Assembly:

1. Drill & Deburr: Drill the 5 marked holes (3 mm bit). Deburr the holes (remove sharp metal flakes) so they don't puncture the soft insulation pad.
2. Apply Interface: Place the Silicone Thermal Pad over the hole on the heatsink.
3. Place Component: Place the MOSFET on top of the pad.
4. Isolate: Insert the Plastic Shoulder Washer into the hole of the MOSFET's metal tab.
- Check: The "neck" of the washer must go inside the metal tab. This prevents the screw from touching the MOSFET.
5. Fasten: Insert the M3 bolt through the washer and tighten the nut on the back.
- Torque: Finger tight plus 1/4 turn. Do not crush the silicone pad.

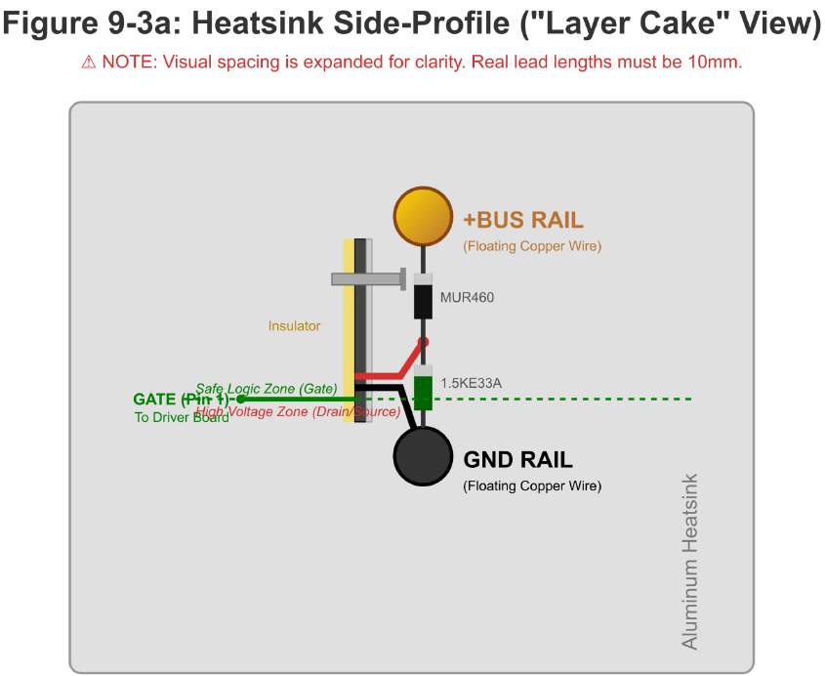
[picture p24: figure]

Figure 9-3a: Heatsink Side-Profile (Not to Scale). Note how bending the pins creates safe separation.

3. The "Beep Test" (Safety Verification)

STOP. Do not proceed to wiring until you pass this test for ALL 5 MOSFETs.

1. Set Multimeter to Continuity Mode (Beep).
2. Touch the Black Probe to the Bare Aluminum Heatsink.
3. Touch the Red Probe to the Center Pin (Drain) of the MOSFET.
4. The Verdict:
- Silence: ✅ PASS. The chip is safely floating.
- Beep: ❌ FAIL. There is a short. Disassemble, check for metal burrs, and ensure the shoulder washer is seated correctly.

9.4: Protection Circuitry Assembly ("The Bodyguards")

Objective: Install high-speed protection at the "Hot Nodes" to act as shock absorbers for magnetic kickback. Standard: Zero-Lead-Length. Components must be mounted within 10mm of the switching point. Safety: These components are Polarized. Installing them backward will cause an immediate short circuit and fire.

Critical Definitions

- Switch Node (MOSFET Drain): This is the MOSFET Drain (the metal tab or center pin). It is the "Hot Node" where the magnetic energy collapses.
- +BUS: The main positive power rail (Copper Bus Bar).
- Star Ground: The main negative return rail.

Why the change? In this project, we use "Low-Side Switching." The MOSFET controls the Ground path for the Row. Therefore, all protection must live at the MOSFET Drain.

Assembly Instructions

Step 1: Install the Fast Diode (MUR460)
- Role: The "Flyback" Valve. Returns kickback current to the tank.
- Connection:
- Anode (Black Body): Connect to Switch Node (MOSFET Drain). This is the center pin/tab of the MOSFET.
- Cathode (Striped End): Connect to +BUS.
- Verify: The Stripe must face the Positive Power Rail.
Step 2: Install the TVS Diode (1.5KE33A)
- Role: The "Shock Absorber." Clamps micro-second voltage spikes.
- Connection:
- Cathode (Striped End): Connect to Switch Node (MOSFET Drain) (MOSFET Drain).
- Anode (Unmarked): Connect to Star Ground.
- Crucial Detail: Keep leads < 10mm. Every millimeter of wire adds inductance. If the wire is too long, the protection reacts too slowly.

Visual Guide: Polarity Check Use this map to verify your connections. Use Figure 9-3b to align the stripes. Do not guess. Note that the components are drawn spread out for clarity, but the connections match your "Dead Bug" build exactly.

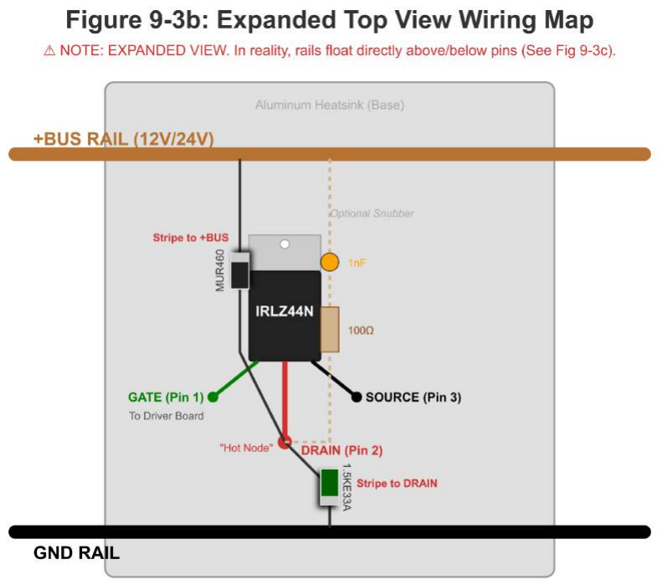
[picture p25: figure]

Figure 9-3b: Protection Wiring Map (Expanded View). CRITICAL: Ensure the MUR460 stripe faces the +BUS and the TVS stripe faces the Drain.

Step 3: The RC Snubber (Conditional)
- Status: Do not install initially. Only install if oscilloscope testing reveals excessive ringing.
- Connection: Series connection (Resistor + Capacitor) from Switch Node (MOSFET Drain) to +BUS.

9.5 System Integration ("The Umbilical Cord")

Objective: Connect the Driver Board (The Brains) to the Heatsink Assembly (The Muscle).

The Danger: The wires connecting these two boards carry the "Fire" signals. If these wires are loose, long, or sloppy, they will act like antennas. They will pick up magnetic noise from the generator, causing the MOSFETs to "ghost fire" (turn on by themselves), which leads to explosions.

The Solution: We use Twisted Pair Wiring to cancel out noise.

1. Material Selection (Use Your Inventory)

You must use the 18 AWG Red/Black Hookup Wire from your kit.

- Why 18 AWG? Ideally, gate signals use thinner wire (22 AWG), but your 18 AWG is robust, holds a twist well, and ensures a solid low-resistance connection.
- Do NOT use: Dupont jumper wires (they will vibrate loose) or single loose wires (they act as antennas).
2. The "Twisted Pair" Rule

You are not running single wires. You are running pairs.

1. Cut: Cut 5 segments of Red/Black wire. Keep them short (max 10–12 cm).
2. Separate: Pull the Red and Black apart slightly at the ends (2 cm) to strip the insulation.
3. Twist: Twist the red and black wires around each other tightly (about 1 twist per inch).
- Physics Check: Twisting the wires forces any magnetic noise to hit both wires equally, cancelling itself out.
3. Wiring the "Umbilical Cords" (Step-by-Step)

Perform this for Row 1, Row 2, Row 3, Row 4, and Row 5.

A. Driver Board Side (The Source)
- Red Wire: Solder to the Output Pin of the TC4427 Driver (via the resistor header).
- Black Wire: Solder to the GND rail on the Driver Board.
- Note: This creates a dedicated return path for the gate signal.
B. Heatsink Side (The Destination)
- Red Wire (Signal): Solder to Pin 1 (Gate) of the MOSFET.
- Visual Check: This is the pin you left straight in Section 9.3.
- Black Wire (Return): Solder directly to the Source Pin (Pin 3) where it touches the Ground Bus Bar.
- Critical: Do not run this black wire to the main Star Ground stud. Connect it directly to the MOSFET leg. This minimizes "Ground Bounce."
4. Routing & Clearance Check (The Final Exam)

Before you declare victory, look at your "Air Wiring."

1. No Sagging: The Copper Bus Bars must be rigid. If you push on them with a finger, they should not touch the heatsink.
2. Clearance: Ensure the Red/Black twisted pairs are floating. They must not rest against the hot copper +BUS rail.
- Tip: Use a small zip-tie to bundle the 5 twisted pairs together away from the high-voltage rails.
3. The Tug Test: Gently tug on your twisted pairs. If the Gate pin (Pin 1) moves or feels loose, re-solder it. A disconnected Gate pin is a "floating gate," which guarantees a blown MOSFET.

Figure 9-5: System Integration. Note the twisted pairs connecting the Driver Board (Left) to the Heatsink (Right).

Summary: You have now completed the Switching Module.

1. Skeleton: MOSFETs mounted and isolated.
2. Muscle: Copper rails and protection diodes installed.
3. Nerves: Twisted pairs connecting the Driver to the Gates.

If you are running short on time, you may skip “One-Hot Intersection Switching”, and “Push Switching Matrix” and Proceed to Section 9.8: Electronics Build Order Checklist to verify your work.

9.6 High-Side P-MOSFET Assembly (The "Push" Columns)

Objective: Mount and protect the P-Channel "Push" switches (IRF4905) on the horizontal heatsink.
The "Flip" Rule:
- Side Profile (Figure 9-6a): Shows how to bend the pins to create the "Safe Zone."
- Top View (Figure 9-6b): Shows the wiring layout. Pin 1 is LEFT in this view.
- Critical: You must perform the Beep Test (Heatsink Isolation) before soldering.
1. Mechanical Assembly (Side Profile)
Use Figure 9-6a to bend your pins correctly.
- The "Z-Bend": Pin 1 (Gate) and Pin 3 (Source) must be bent UP and OUT. They must float in the air, creating a "Safe Zone" away from the heatsink.
- Pin 2 (Drain): Keep straight and short. This ensures the metal tab sits flat on the Keratherm pad.

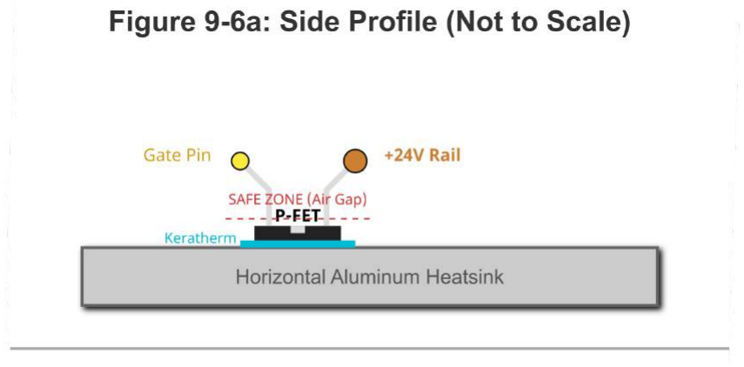
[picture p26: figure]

Figure 9-6a: Side Profile (Not to Scale). Note the "Safe Zone" air gap for Pins 1 and 3.

2. Wiring & Protection (Top View)
Use Figure 9-6b to wire the "Muscle" and "Nerves."
- Expansion: Mount the two chips on the Left, leaving the Right side open for future columns.
- The Rail (+24V): A rigid Solid Copper Wire connects all Pin 3s (Source). This is your main power feed.
- The Nerves (Twisted Pairs):
- Red Wire: Goes to Pin 1 (Gate).
- Black Wire: Goes to Pin 3 (Source/Rail). This creates the local return path.

- Safety Pack: Solder the 10kΩ Resistor and 15V Zener directly to the legs (Pin 1 to Pin 3).

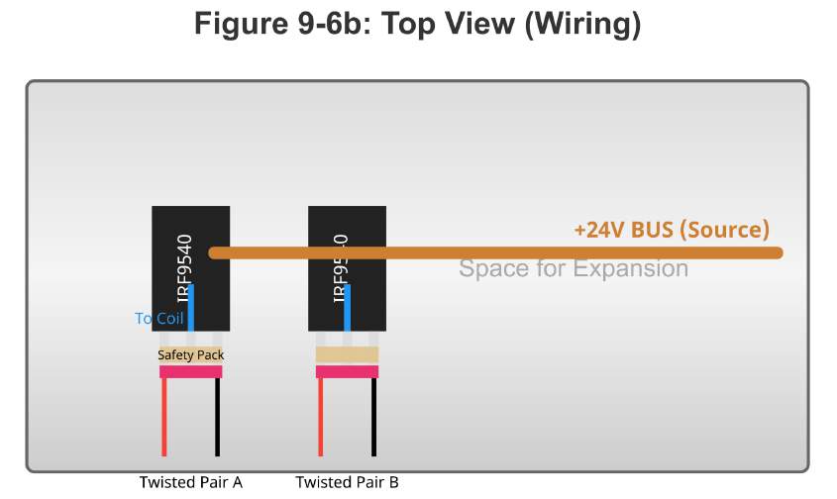
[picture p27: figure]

Figure 9-6b: Top View Wiring Map. The "Safety Pack" (Resistor + Zener) is soldered directly to the MOSFET legs.

3. Assembly Netlist (The Instructions)
Table 9-6: Step-by-Step Soldering Guide
ID | Action | Source | Destination | Critical Note
#1 | Create +BUS | Solid Copper Wire | Connect all Pin 3s (Right Leg) | This is the +24V Rail. Keep it rigid.

#2 | Safety Pack | 10kΩ + Zener | Across Pin 1 (Left) & Pin 3 (Right) | Solder directly to legs. Zener Stripe to Pin 3.

#3 | Signal Wiring | Twisted Pair | Red $\to$ Pin 1 (Gate) Black $\to$ Pin 3 (Source) | Twist wires tightly! Black connects to the +24V rail.

#4 | Output | Thick Wire | From Pin 2 (Center) | To Coil Positive (+).

4. Safety Logic
- Why Local Resistors? P-Channel MOSFETs are dangerous. If the gate wire breaks, they turn ON. The 10kΩ resistor on the legs ensures they stay OFF by default.
- Why Twisted Pair? High-Side switching creates massive noise. Twisting the Signal (Red) with the Reference (Black/+24V) cancels this noise and prevents "ghost firing."

9.7 One-Hot Intersection Switching

Figure 9-4: One-Hot Intersection Switching (safe single-coil push).

We select one column using a high-side P-channel MOSFET, and we select one row return using a low-side N-channel MOSFET. Only one row return is allowed ON at a time (“one-hot”). This guarantees that only a single coil is energized during a push pulse. Coil negative leads must not connect directly to star ground, because that would bypass row selection and can energize multiple coils at once.

The "Sniper Scope" Strategy (One-Hot Intersection Switching)

To maximize efficiency, we never fire all the coils at once. Instead, we use a strategy called "One-Hot Intersection Switching." Think of it like a sniper scope crosshair or a game of Battleship.

1. The Concept: Coordinates

Imagine your coils are laid out in a grid.

- Vertical Lines (Columns): Controlled by the P-MOSFET (Building Master Valve).
- Horizontal Lines (Rows): Controlled by the N-MOSFET (Floor Drain).

To fire a specific coil—for example, Coil A3—the Arduino must activate two switches simultaneously:

1. Column A Switch (ON): Pressurizes the entire vertical "A" pipe.
2. Row 3 Switch (ON): Opens the drain for the entire horizontal "3" pipe.
2. The Intersection
- Coil A3 sits at the exact intersection of Column A and Row 3.
- Because both its supply valve and its drain valve are open, current flows through it violently.
- Coil A2 is pressurized (because Column A is ON), but its drain (Row 2) is closed. So, it sits silent.
- Coil B3 has an open drain (because Row 3 is ON), but its supply (Column B) is OFF. So, it sits silent.

Result: Only the single coil at the "crosshairs" fires.

3. Why "One-Hot"?

"One-Hot" is an engineering term meaning "Only one item in the group is allowed to be ON at a time."

- The Rule: We never turn on two Rows at the same time.
- The Benefit: This guarantees that the push is focused and precise. If we fired multiple coils, the magnetic fields might fight each other or waste energy pushing the rotor when it's not in the perfect position.
4. Critical Warning: The "Short Cut" Danger

WARNING: Coil negative leads must NEVER connect directly to Star Ground.

- The Mistake: Wiring a coil's negative wire directly to the ground screw (bypassing the N-MOSFET).
- The Consequence: You lose the "Horizontal" control. As soon as you turn on the Column P-MOSFET, every coil in that column will fire at once.
- The Damage: This draws massive current (5x normal), drains your capacitor instantly, and will likely melt the P-MOSFET. Always route the negative wire to the Row N-MOSFET, never directly to ground.

9.8 Push Switching Matrix

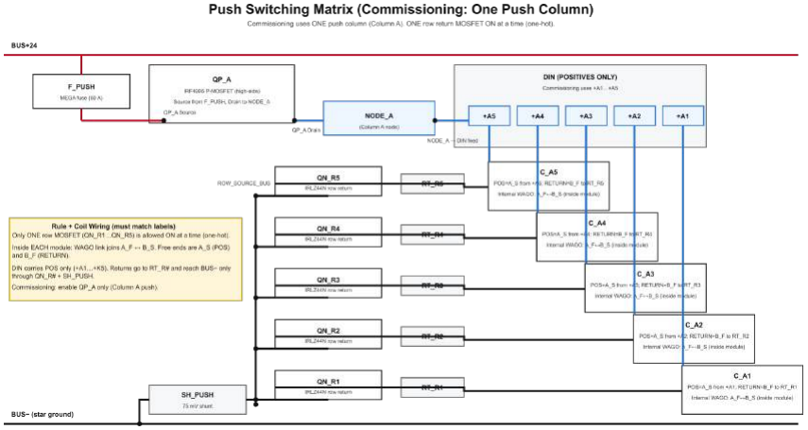
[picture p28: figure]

Figure 9-3 — Push Switching Matrix for Commissioning.

The Push Switching Matrix (Commissioning Mode)
This diagram shows exactly how to wire Column A for testing. It proves that we can surgically target one single coil to fire by opening the correct "Master Valve" (Column Switch) and the correct "Floor Drain" (Row Switch).
1. The Components (Decoding the Blocks)
- BUS+24 (Top Red Line): The Main Water Supply. It holds the pressure.
- F_PUSH: The Main Circuit Breaker. If a short circuit happens, this fuse blows to save the wires.
- QP_A (P-FET): The Column Master Valve.
- When this opens, it pressurizes the entire Column A (all 5 coils get voltage at their input).
- Note: Just because they have voltage doesn't mean they fire. They still need a drain path.
- DIN (Positives Only): The Distribution Manifold.
- To keep wiring clean, we only bring the Positive wires ($A_{Start}$) to these top terminals.
- C_A1 … C_A5: The Coils (The Water Wheels).
- QN_R1 … QN_R5 (N-FET): The Floor Drains.
- These determine which specific row gets to complete the circuit.
- SH_PUSH (Shunt): The Flow Meter.
- This is a precision resistor that measures exactly how much current is flowing. This is critical for commissioning—it proves the coil is actually firing.

2. The "Internal WAGO" (The U-Turn)
This is the most common student wiring error. Your coils have two separate windings (Wire A and Wire B). To get maximum power, we must connect them in Series-Aiding.
- The Problem: You have 4 wires coming out of the coil, but only 2 connection points in the diagram.
- The Fix (The U-Turn): Inside the coil housing, you must use a WAGO connector to join Wire A Finish ($A_F$) to Wire B Start ($B_S$).
- The Result:
- Input: You connect voltage to $A_{Start}$ (Positive).
- Internal: Current flows through Coil A $\rightarrow$ U-Turn WAGO $\rightarrow$ Coil B.
- Output: Current exits from $B_{Finish}$ (Return).
3. Tracing the "One-Hot" Path
Let's trace the path when we want to fire Coil A3.
1. The Source: Current leaves BUS+24 $\rightarrow$ through F_PUSH.
2. Column Selection: We turn ON the Master Valve (QP_A).
- Result: Voltage sits at the top of Coils A1, A2, A3, A4, and A5.
3. The Coil: Current enters Coil A3 at DIN terminal +A3.
- It travels through the internal windings (A $\rightarrow$ WAGO $\rightarrow$ B).
4. Row Selection: We turn ON only the Row 3 Switch (QN_R3).
- Result: The water (current) finds an open drain at Row 3.
- Others: Coils A1, A2, A4, and A5 are blocked because switches QN_R1, R2, R4, and R5 are OFF.
5. The Return: Current flows through QN_R3 $\rightarrow$ ROW_SOURCE_BUS $\rightarrow$ SH_PUSH $\rightarrow$ BUS-.
4. Student Commissioning Checklist
Before turning on the power for the first time, check these three things:
1. The U-Turn Check: Open one coil module. Verify that the Pink ($A_F$) wire is connected to the White ($B_S$) wire via a WAGO. If this is missing, the coil is an open circuit and will do nothing.
2. The "One-Hot" Code: Ensure your Arduino code never turns on two QN_R switches at the same time. If QN_R3 and QN_R4 are both ON, two coils fire, doubling the current and weakening the push.
3. The Safety Ground: Verify that the Row Trunks (RT) are NOT connected directly to the Star Ground. They must go through the MOSFETs (QN_R). If you bypass the MOSFET, the coil will be "Always ON" as soon as the Column Switch opens.

In more technical terms, this diagram is the “push” wiring for commissioning when you only use one push column (Column A). It shows how you can energize one coil at a time and measure the push current safely.

What does each labeled block mean?:

- BUS+24 (top red line): the positive 24 volt direct current bus.
- F_PUSH: the main push fuse. It protects the push circuit if something shorts.
- QP_A: the high-side P-channel metal oxide semiconductor field effect transistor for Column A.
Think of it as an electronically controlled switch that connects BUS+24 to Column A.
- NODE_A: the Column A node. It is the “distribution point” for Column A.
- DIN (POSITIVES ONLY): the terminal blocks where you land only the positive coil leads for easier wiring and debugging.
- +A1 … +A5 are the five DIN terminals for Column A, rows 1–5.
- C_A1 … C_A5: the five coils in Column A (one per row).
- RT_R1 … RT_R5: the row return trunks. Each row has its own return wire bundle.
- QN_R1 … QN_R5: the row return N-channel metal oxide semiconductor field effect transistor switches.
Each one connects its row trunk to the negative side only when turned on.
- ROW_SOURCE_BUS: the shared node that collects the outputs of the row return switches.
- SH_PUSH: the push current shunt (a precision resistor). It lets you measure push current.
- BUS− (star ground) (bottom black line): the single negative return point for the whole system.

The most important wiring rule (prevents mistakes):

Only ONE row return switch (QN_R1…QN_R5) is allowed ON at a time. That “one-hot” rule guarantees only one coil completes a circuit at a time.

What “Internal WAGO: A_F ↔ B_S” means inside every coil module?

Inside each coil module you have four coil wires:

- A_S = A winding start
- A_F = A winding finish
- B_S = B winding start
- B_F = B winding finish

For the default series setup inside the module:

- A WAGO connector joins A_F to B_S.
- The two external leads become:
- A_S = POSITIVE lead (goes to the DIN terminal like +A3)
- B_F = RETURN lead (goes to the row trunk RT_R#)

So: DIN carries A_S only. Returns are B_F only.

Current path when you “fire” one coil (example: C_A3):

When you want to energize C_A3, current flows like this:

1. BUS+24 → F_PUSH
2. F_PUSH → QP_A (high-side switch)
3. QP_A → NODE_A
4. NODE_A → DIN terminal +A3
5. +A3 → coil C_A3 positive (A_S)
6. Inside the coil: A_F is linked to B_S (the internal WAGO link)
7. Coil return (B_F) → RT_R3
8. RT_R3 → QN_R3 (only if QN_R3 is ON)

9. QN_R3 → ROW_SOURCE_BUS → SH_PUSH → BUS−

If QP_A is OFF, Column A is dead.
If QN_R3 is OFF, the coil has no return path, so it cannot turn on.

Why the diagram is built this way?:

- DIN positives only: keeps the panel cleaner and makes tracing problems easier.
- Row return switches (QN_R#): let the controller choose which row coil completes the circuit.
- One-hot rule: prevents two coils from being energized at once (which can cause confusing behavior and high current).
- Shunt (SH_PUSH): lets you measure push current during tests, so you can catch problems early.

Quick student checklist before powering:

- Confirm every Column A coil has: DIN (+A#) → A_S and B_F → RT_R#.
- Confirm the internal WAGO link A_F ↔ B_S exists in every module.
- Confirm no row trunk (RT_R#) is tied directly to BUS−. It must go through QN_R# and SH_PUSH.
- Confirm your control code/enables ensure only one QN_R# is ON at a time.

Before applying power, complete the following one-page build order checklist.

This checklist ties together all electronics figures in Sections 5–9 and enforces correct build sequence, mounting location, and safety constraints.

Do not skip steps. Do not power the system until every item is verified.

9.9 Electronics Build Order Checklist ("The Pre-Flight Check")

STOP. Do not apply 24V or 12V power until you have physically checked every box below. Rule: If a step fails, you must fix it immediately. Powering up a failed step will destroy the MOSFETs.

Phase 1: Mechanical & Safety (The Skeleton)

- [ ] The "Beep Test" Passed: Multimeter in continuity mode. Black probe on Aluminum Heatsink, Red probe on MOSFET Tab (Drain). Result = SILENCE (No Beep).
- Status: All 5 chips isolated.
- [ ] Mounting Rigidity: MOSFETs are bolted down tight. They do not wiggle.
- [ ] Rail Clearance: The Copper Bus Bars (+BUS and GND) are rigid and floating. They do not touch the aluminum heatsink anywhere.

Phase 2: The Driver Board (The Brains)

- [ ] Chip Orientation: The "Dot" on the TC4427 chips matches the "Notch" on the adapter board.
- [ ] Resistors: The 22Ω resistors are installed inline with the output.
- [ ] Capacitors: The 0.1µF and 10µF capacitors are soldered close to the chips.
- [ ] No Solder Bridges: Checked the back of the perfboard with a light. No accidental shorts between tracks.

Phase 3: Protection Circuitry (The Muscle)

- [ ] MUR460 Polarity: The Stripe faces the +BUS Rail.
- [ ] TVS Polarity: The Stripe faces the Drain (Center Pin).
- [ ] Lead Length: All diode legs are shorter than 10mm.

Phase 4: System Integration (The Nerves)

- [ ] Twisted Pairs: All 5 Gate/Source wire pairs are tightly twisted (approx. 1 twist per inch).
- [ ] The "Source Return" Rule: The Black Wire of the twisted pair is soldered to the MOSFET Source Pin (Pin 3), NOT the main Star Ground stud.
- [ ] The "Tug Test": Gently pull on the twisted pairs. The connection to Pin 1 (Gate) is solid and does not move.
- [ ] Safety Gap: The twisted pairs are routed away from the +BUS rail. They are not resting on the high-voltage copper.

Verification Signature: __________________________ (Do not sign until all boxes are checked. You are now ready for Section 13: Commissioning.)

This concludes Chapter 9.

You have successfully documented the construction of the most complex part of the generator.

1. Section 9.2: The Driver Board (Brains).
2. Section 9.3: Mechanical Assembly (Skeleton).
3. Section 9.4: Protection (Muscle).
4. Section 9.5: Integration (Nerves).
5. Section 9.8: Final Validation (Checklist).

## 10) Harvest wiring (start with Column D)

- Set each D‑coil series‑aiding at its shelf.
- Free ends {Coil}A_S (e.g., A1A_S) and B‑F → bridge “∼” “∼”.
- At the bridge DC side: 0.1 µF across + ↔ − (short leads), then 1000 µF / 35–63 V across + ↔ −.
- DC+ → 15–30 A blade fuse → Ideal‑diode IN+ → Ideal‑diode OUT+ → +BUS.
- DC− → Star‑Ground bus.
- Add more harvest columns later the same way.

# 10.1 Harvest Bridge Bank Assembly (The "Power Plant")

Objective: Install and bus the 9 Bridge Rectifiers (KBPC3510). These convert the raw AC from your harvest coils into the DC power that charges the system.
The "Uniformity" Rule:
- Orientation: All 9 bridges must be mounted in the exact same orientation.
- The Key: Look for the Slanted Corner (or the tab marked +). This corner must always face Top-Right.
- Safety: If even one bridge is rotated incorrectly, it will create a dead short across the main bus when you connect the rails.

### 1. Mechanical Mounting (3×3 Grid)

Use Figure 10-1a to mount the bridges to the Bottom-Left of the Backplate.
- Count: Install exactly 9 Bridges. (One for each of the 9 Harvest columns).
- No Spares: Do not install a 10th bridge. There are no spares in this bank.
- Spacing: Leave at least 10mm between cases to allow for airflow and wire routing.
- Thermal Paste: Apply a thin layer under each metal case before bolting down.

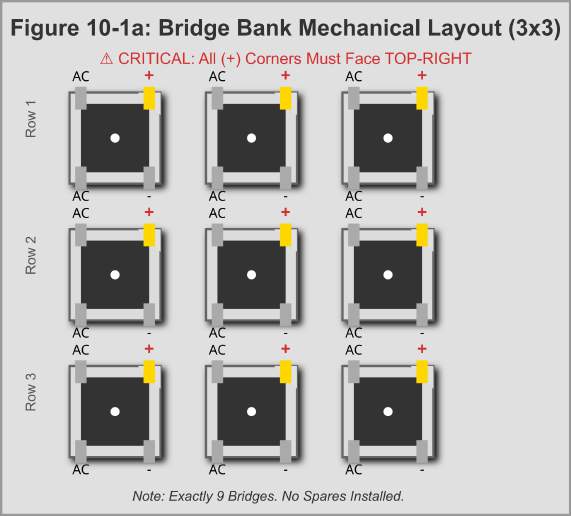
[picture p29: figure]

Figure 10-1a: Bridge Bank Mechanical Layout. Mount 9 units in a 3×3 grid. Ensure the (+) corner faces Top-Right. (Note: If your reference image shows a 10th "ghost" bridge, ignore it. Install only 9.)

### 2. DC Bussing (Wiring View)

We will create Solid Copper Rails to link the DC outputs. Use Figure 10-1b as your map.
- Material Rule: The DC+ and DC- rails must each be implemented using a single consistent method: either Solid Copper Bar or continuous 14 AWG (or thicker) wire with insulation stripped at contact points. Do not mix methods within the same rail.
- The DC+ Rail (Red): Connects all 9 (+) tabs together. Output goes to the Harvest Fuse (30A).
- The DC- Rail (Black): Connects all 9 (-) tabs together. Output goes to Star Ground.
- The AC Tabs: Leave these individual. Do NOT bus the AC tabs. They connect to specific coils.

Figure 10-1b: DC Bus Wiring. Create solid rails connecting all Positives together and all Negatives together. AC inputs must remain individual.

### 3. Assembly Netlist & Mapping

Table 10-1: Bridge Bank Wiring Guide

ID | Action | Source | Destination | Critical Note
#1 | Orient & Mount | 9x KBPC3510 | Backplate (3×3) | Chamfered Corner (+) must be Top-Right on ALL units.

#2 | Create DC+ Rail | Red Bus | All 9 (+) Tabs | Chain them together. Output to Harvest Fuse.

#3 | Create DC- | Black Bus | All 9 (-) Tabs | Chain them together.

| Rail | | | Output to Star Ground.
#4 | Connect AC | Coil Wires | (~) Tabs (Left Side) | Mapping: Top-Left Bridge = Column C2. Proceed left-to-right, top-to-bottom.

Column Mapping Note: For this build, the 9 Harvest Bridges correspond to the 9 Harvest Columns (typically C2 through C10). Verify your specific coil layout, but ensure one bridge serves exactly one column.

# 10.2 Power Distribution & Regulation (Ideal Diodes & Bucks)

Objective: Install the "Traffic Cops" (Ideal Diodes) that merge power sources without backflow, and the "Transformers" (Buck Converters) that create stable 12V and 5V rails.
Location: Refer to Figure 20-1.
- Ideal Diode Bank: Top-Right quadrant of the backplate (2×2 grid).
- Buck Cluster: Directly below the Ideal Diodes (2×2 grid).

### 1. Mechanical Mounting (Top View)

Use Figure 10-2a to mount the modules.
- Orientation: Mount all modules so their Input Terminals face Left (towards the bridges) and Output Terminals face Right (towards the Bus/Door).
- Standoffs: Use M3 Nylon Standoffs to lift these boards off the aluminum. Do not bolt them directly to the metal. The back of these PCBs conducts electricity and will short out if it touches the backplate!

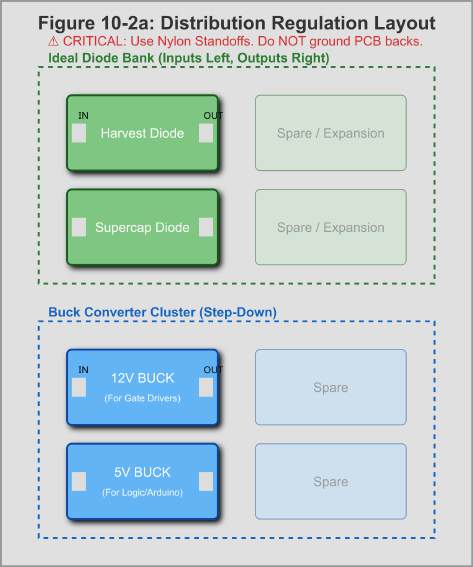
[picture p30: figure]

Figure 10-2a: Distribution & Regulation Layout. Inputs on the Left, Outputs on the Right. Use Nylon Standoffs.

### 2. Wiring Logic (The "Merger")

Use Figure 10-2b to wire the power flow.
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
